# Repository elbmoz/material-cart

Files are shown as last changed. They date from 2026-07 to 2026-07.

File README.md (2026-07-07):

# Material Cart

物料搬运小车项目资料仓库，包含嵌入式控制程序、机械结构模型和 PCB 制板文件。

本项目面向竞赛机器人/物料搬运车场景，主要功能包括麦克纳姆轮底盘运动控制、Z 轴升降、舵机/机械臂抓取、视觉定位、二维码任务解析和按颜色/位置完成抓取放置流程。

## 仓库内容

```text
material-cart/
├── gc-z7-code/     STM32F407 控制程序与 Keil 工程
├── model/          SolidWorks 机械装配体与零件模型
├── 制板文件/       PCB Gerber 压缩包
└── README.md       项目说明
```

## 嵌入式工程

控制程序位于 `gc-z7-code/`，使用 STM32CubeMX 生成，目标芯片为 `STM32F407VETx`，工具链为 Keil MDK-ARM。

常用入口：

| 文件/目录 | 说明 |
|---|---|
| `gc-z7-code/MDK-ARM/gc.uvprojx` | Keil uVision 工程文件 |
| `gc-z7-code/gc.ioc` | STM32CubeMX 配置文件 |
| `gc-z7-code/Core/Inc/` | 用户头文件 |
| `gc-z7-code/Core/Src/` | 用户源文件 |
| `gc-z7-code/Drivers/` | STM32 HAL 与 CMSIS 驱动 |
| `gc-z7-code/MDK-ARM/gc/` | Keil 编译输出目录 |

### 打开与编译

1. 安装 Keil MDK-ARM。
2. 打开 `gc-z7-code/MDK-ARM/gc.uvprojx`。
3. 选择目标工程后编译。
4. 通过 ST-Link / SWD 下载到 STM32F407 控制板。

当前仓库未配置命令行构建脚本，建议直接使用 Keil uVision 编译和烧录。

### 主要模块

| 模块 | 作用 |
|---|---|
| `Motor_Move.c/.h` | 底盘运动、麦克纳姆轮解算、Z 轴升降控制 |
| `GC_Chassis_Control.c/.h` | 底盘 PID、定距直行、原地转向、视觉定位控制 |
| `PID.c/.h` | 通用 PID 算法 |
| `zhangdatou.c/.h` | 步进电机驱动通信 |
| `HWT101.c/.h` | HWT101 IMU 姿态角读取 |
| `serial.c/.h` | 视觉模块串口通信 |
| `LobotServoController.c/.h` | 幻尔串口舵机控制 |
| `huaner_servo.c/.h` | 舵机预设动作 |
| `ServoMotorControl.c/.h` | 视觉辅助的舵机精定位 |
| `QRcode.c/.h` | 二维码任务读取 |
| `action.c/.h` | 比赛动作流程编排 |

## 机械模型

机械模型位于 `model/`，主要包含 SolidWorks 装配体和零件文件：

| 类型 | 扩展名 | 说明 |
|---|---|---|
| 装配体 | `.SLDASM` | 小车整体、局部机构装配 |
| 零件 | `.SLDPRT` | 结构件、支架、轮组、机械臂等 |
| 通用模型 | `.stp` | 可跨 CAD 软件导入的模型文件 |

建议使用 SolidWorks 打开根装配体，例如 `model/1.SLDASM` 或 `model/xyz版.SLDASM`。

## 制板文件

PCB 制板文件位于 `制板文件/`，目前包含多个 Gerber 压缩包：

| 文件 | 说明 |
|---|---|
| `Gerber_主板.zip` | 主控板制板文件 |
| `Gerber_openmv转接板.zip` | OpenMV 转接板制板文件 |
| `Gerber_塔吊转接板.zip` | 塔吊/机构转接板制板文件 |
| `Gerber_幻尔转接板.zip` | 幻尔舵机/模块转接板制板文件 |
| `Gerber_烧录转接板.zip` | 烧录转接板制板文件 |

下单制板前建议先用 Gerber 查看器检查层定义、孔位、板框和丝印。

## 硬件与通信简表

| 外设/接口 | 用途 |
|---|---|
| USART1 | 步进电机驱动通信 |
| USART2 | HWT101 IMU |
| UART5 | 视觉模块 / 蓝牙调试通信 |
| USART6 | 幻尔串口舵机 |
| TIM2 | 1 ms 定时中断 |
| TIM3 | PWM 舵机输出 |
| PE7 | 限位开关输入 |

## 使用建议

- 修改 STM32 外设配置时，优先编辑 `gc-z7-code/gc.ioc` 并通过 STM32CubeMX 重新生成。
- 自定义代码应尽量放在 `/* USER CODE BEGIN */` 和 `/* USER CODE END */` 区域内，避免重新生成时被覆盖。
- 机械模型包含较多中文文件名，跨系统传输时注意编码和路径兼容性。
- 当前仓库保留了部分 Keil 编译产物，便于复现原始工程状态；后续如果只维护源码，可以再添加 `.gitignore` 精简仓库。

## 许可

仓库当前未声明开源许可证。未经项目成员确认前，请勿默认用于商业发布或二次分发。

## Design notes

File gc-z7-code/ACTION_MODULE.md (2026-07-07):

# action 模块说明

本文用于快速理解 `Core/Src/action.c` 和 `Core/Inc/action.h` 的作用、对外接口和在 `GC_task.c` 中的调用方式。

## 1. 模块定位

`action` 模块是比赛动作编排层。

它不直接实现底层电机通信、PID 算法或舵机协议，而是把已有基础动作组合成完整比赛流程：

- 舵机预设动作：来自 `huaner_servo.h`
- Z 轴升降/回零：来自 `Motor_Move.h`
- 视觉找物块：来自 `ServoMotorControl.h`
- 底盘定位移动：来自 `GC_Chassis_Control.h`
- 动作等待：来自 `delay.h`

一句话理解：

```text
二维码任务 -> 视觉找物块 -> 抓到车上槽位 -> 从车上取出 -> 按颜色放地面 -> 再从地面回收到车上
```

## 2. 任务值含义

`action.c` 当前只处理 3 个颜色任务：

```c
#define ACTION_QRCODE_TASK_COUNT 3U
#define ACTION_PLACE_SIDE_OFFSET_MM 152.0f
```

任务值必须是 `1~3`，非法值会被跳过。

地面放置位置映射：

| task | 含义 | 地面 X 目标位置 |
|---|---|---|
| `1` | 红色 / 左侧 | `-152mm` |
| `2` | 绿色 / 中间 | `0mm` |
| `3` | 蓝色 / 右侧 | `+152mm` |

注意：`task1/task2/task3` 表示颜色任务顺序，不直接表示车上槽位。车上槽位由数组下标决定：

```text
第 1 个 task -> 车上槽 1
第 2 个 task -> 车上槽 2
第 3 个 task -> 车上槽 3
```

## 3. 推荐在 GC_task 中调用的接口

这些是 `action.h` 中最适合流程状态机调用的高级接口。

### Action_RunQRCodeTasks

```c
void Action_RunQRCodeTasks(uint8_t task1, uint8_t task2, uint8_t task3);
```

作用：按二维码给出的 3 个颜色任务，依次视觉找物块并抓到车上 1/2/3 槽。

内部流程：

```text
for each task:
  1. 判断 task 是否为 1~3
  2. ServoMotorVision_Calibrate(task) 视觉找对应颜色
  3. 调用 zhuafang1/2/3() 放到对应车槽
```

典型用途：物料盘抓取阶段。

### Action_PlaceLoadedQRCodeTasks1

```c
void Action_PlaceLoadedQRCodeTasks1(uint8_t task1, uint8_t task2, uint8_t task3);
```

作用：把车上 1/2/3 槽的物块取出来，按颜色放到地面左/中/右位置。

内部流程：

```text
for each task:
  1. 从车上第 i 个槽取物块
  2. 根据 task 计算地面 X 位置
  3. FieldPos_Block() 横向移动到目标位置
  4. 使用第一套高度放到地面
```

第一套放置高度中，Z 轴下降较深：

```c
ZAxis_MoveRelative(-13000, 200, 4000);
```

典型用途：第一轮地面放置。

### Action_PlaceLoadedQRCodeTasks2

```c
void Action_PlaceLoadedQRCodeTasks2(uint8_t task1, uint8_t task2, uint8_t task3);
```

作用：和 `Action_PlaceLoadedQRCodeTasks1()` 类似，也是把车上物块放到地面指定颜色位置。

区别：使用第二套放置高度，Z 轴下降较浅：

```c
ZAxis_MoveRelative(-7000, 200, 4000);
```

典型用途：第二轮放置或叠放阶段。

### Action_RecoverGroundQRCodeTasks

```c
void Action_RecoverGroundQRCodeTasks(uint8_t task1, uint8_t task2, uint8_t task3);
```

作用：按二维码顺序，从地面左/中/右位置把物块抓回车上 1/2/3 槽。

内部特点：

- 先用 `Action_GetLastPlaceX()` 推算当前底盘停在最后一次放置位置。
- 再按任务顺序移动到对应地面位置。
- 第一个回收动作走 `Action_GrabRecoverFirstToCarSlot()`。
- 后续回收动作走 `zhuafang8/9/10()`。

典型用途：地面物块回收到车上。

## 4. 暴露的底层动作脚本

这些函数也在 `action.h` 中暴露，但更适合单动作调试，不建议在正式流程里到处直接调用。

| 接口 | 作用 |
|---|---|
| `zhuafang1()` | 地面抓取并放到车上槽 1 |
| `zhuafang2()` | 地面抓取并放到车上槽 2 |
| `zhuafang3()` | 地面抓取并放到车上槽 3，末尾使用 `kanche2()` |
| `zhuafang4()` | 旧版较长组合动作，主流程基本未直接使用 |
| `zhuafang5()` | 槽 2 相关短动作，偏调试 |
| `zhuafang6()` | 槽 3 相关短动作，偏调试 |
| `zhuafang7()` | 视觉/底盘校准前准备动作：Z 轴回零、下降、看地面、松爪、servo13 回零 |
| `zhuafang8()` | 从地面抓回并放到车上槽 1 |
| `zhuafang9()` | 从地面抓回并放到车上槽 2 |
| `zhuafang10()` | 从地面抓回并放到车上槽 3，末尾使用 `kanche2()` |

## 5. 在 GC_task 中的调用方式

`Action_*` 接口都是阻塞式动作。调用后会执行完整机械动作，动作没做完不会返回。

因此在 `GC_task.c` 的 `case` 中调用时，必须调用完立刻切换到下一个状态，避免下一次 `GC_Task_Run()` 重复执行同一动作。

示例：

```c
#include "action.h"

case GC_wuliaopan1:
    Action_RunQRCodeTasks(gc_qr1, gc_qr2, gc_qr3);
    GC_Task_EnterState(GC_kaojinA1);
    break;
```

不推荐这样写：

```c
case GC_wuliaopan1:
    Action_RunQRCodeTasks(gc_qr1, gc_qr2, gc_qr3);
    break;
```

因为状态没有切走，下一次进入 `GC_Task_Run()` 还会再次执行抓取动作。

## 6. 二维码值传入 GC_task 的建议方式

`main.c` 当前可以通过 `QRcode_WaitTaskGroupsAndStop()` 获取 6 个二维码任务。

建议在 `GC_task.c` 中保存这些值：

```c
static uint8_t gc_qr1, gc_qr2, gc_qr3;
static uint8_t gc_qr4, gc_qr5, gc_qr6;

void GC_Task_SetQRCodeTasks(uint8_t t1, uint8_t t2, uint8_t t3,
                             uint8_t t4, uint8_t t5, uint8_t t6)
{
    gc_qr1 = t1;
    gc_qr2 = t2;
    gc_qr3 = t3;
    gc_qr4 = t4;
    gc_qr5 = t5;
    gc_qr6 = t6;
}
```

并在 `GC_task.h` 中声明：

```c
void GC_Task_SetQRCodeTasks(uint8_t t1, uint8_t t2, uint8_t t3,
                             uint8_t t4, uint8_t t5, uint8_t t6);
```

`main.c` 扫码完成后调用：

```c
GC_Task_SetQRCodeTasks((uint8_t)main_qrcode_task1,
                       (uint8_t)main_qrcode_task2,
                       (uint8_t)main_qrcode_task3,
                       (uint8_t)main_qrcode_task4,
                       (uint8_t)main_qrcode_task5,
                       (uint8_t)main_qrcode_task6);
```

之后 `GC_task.c` 中就可以直接使用：

```c
Action_RunQRCodeTasks(gc_qr1, gc_qr2, gc_qr3);
Action_PlaceLoadedQRCodeTasks1(gc_qr1, gc_qr2, gc_qr3);
Action_RecoverGroundQRCodeTasks(gc_qr1, gc_qr2, gc_qr3);

Action_RunQRCodeTasks(gc_qr4, gc_qr5, gc_qr6);
Action_PlaceLoadedQRCodeTasks2(gc_qr4, gc_qr5, gc_qr6);
```

## 7. 可参考的两轮流程

当前 `main.c` 中已有类似流程，可以迁移到 `GC_task.c`：

```text
第一轮 task1~3:
  Action_RunQRCodeTasks
  VisionPrecision_Calibrate
  Action_PlaceLoadedQRCodeTasks1
  Action_RecoverGroundQRCodeTasks
  Action_PlaceLoadedQRCodeTasks1

第二轮 task4~6:
  Action_RunQRCodeTasks
  VisionPrecision_Calibrate
  Action_PlaceLoadedQRCodeTasks1
  Action_RecoverGroundQRCodeTasks
  VisionPrecision_Calibrate
  Action_PlaceLoadedQRCodeTasks2
```

## 8. 接手时优先检查的参数

`action` 模块的大部分问题不是语法错误，而是动作参数和实际机械结构不匹配。

优先检查：

- `ACTION_PLACE_SIDE_OFFSET_MM = 152.0f` 是否对应实际左/中/右间距。
- `ZAxis_MoveRelative()` 的下降/上升脉冲是否安全。
- `servo13_Home(backOffMs)` 的回退时间是否合适。
- `fangche1/2/3()`、`kanche()`、`kanche2()`、`kandi()` 的舵机位置是否和机械臂实际位置一致。
- `Action_PlaceLoadedQRCodeTasks1()` 和 `Action_PlaceLoadedQRCodeTasks2()` 的高度差是否对应第一轮/第二轮需求。

## 9. 总结

正式流程中优先调用：

```c
Action_RunQRCodeTasks(...)
Action_PlaceLoadedQRCodeTasks1(...)
Action_PlaceLoadedQRCodeTasks2(...)
Action_RecoverGroundQRCodeTasks(...)
```

单独调试机械动作时再调用：

```c
zhuafang1() ~ zhuafang10()
```

在 `GC_task.c` 中，每次调用一个 `Action_*` 后都应立即 `GC_Task_EnterState(next_state)`，避免重复执行同一个阻塞动作。

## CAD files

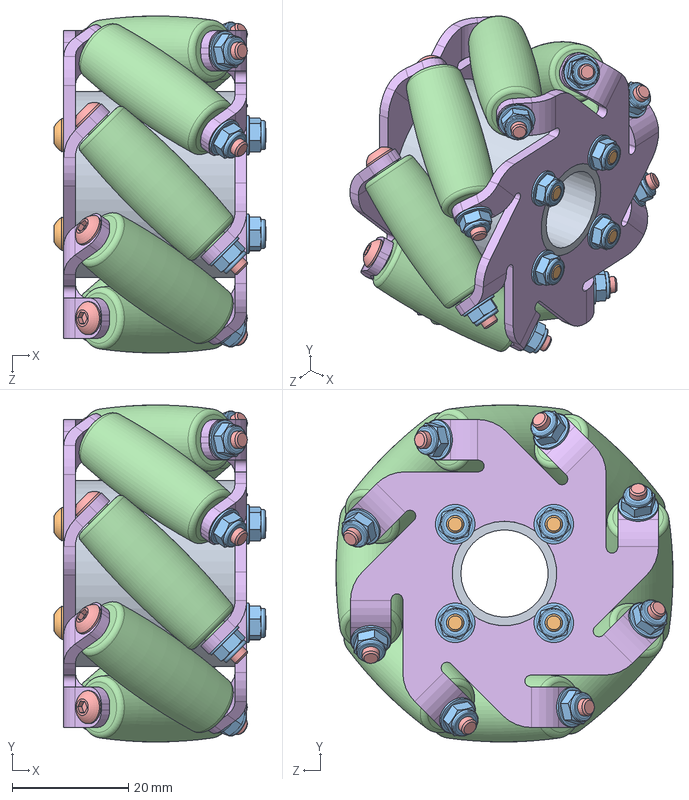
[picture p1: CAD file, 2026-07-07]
model/轮.SLDASM
36.5 x 58.0 x 58.0 mm
中轴
短螺丝 x 4
防松螺丝 x 12
滚轮1 x 8
长螺丝 x 8
支持架 x 2

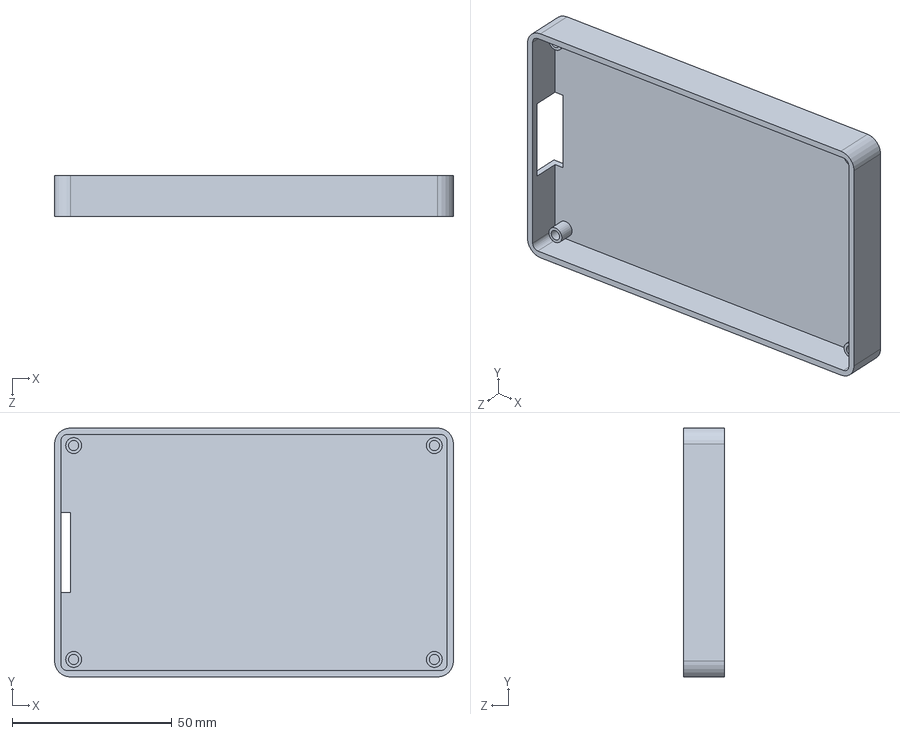
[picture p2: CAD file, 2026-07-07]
model/显示屏.SLDPRT
125.0 x 78.0 x 13.0 mm

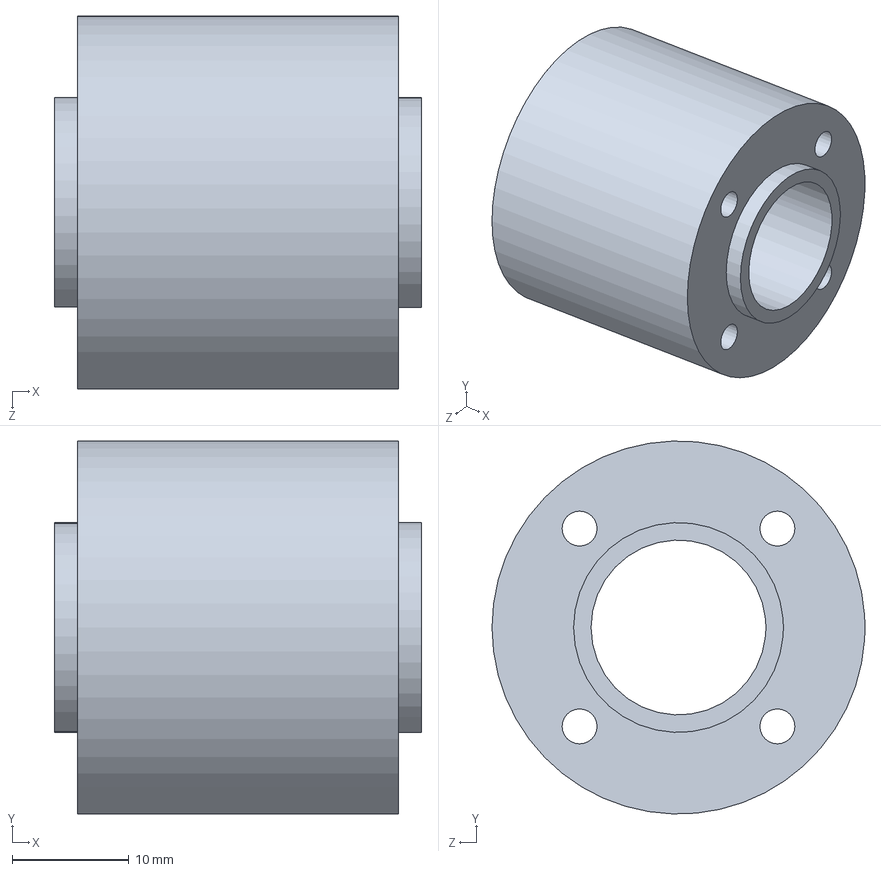
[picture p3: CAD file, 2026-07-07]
model/中轴.SLDPRT
31.5 x 32.0 x 32.0 mm

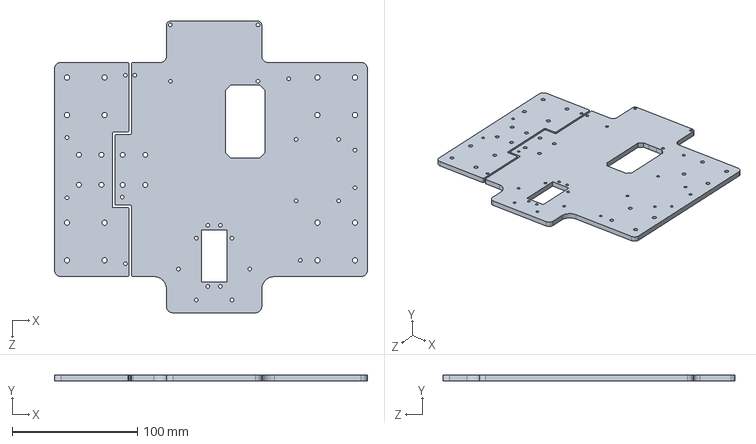
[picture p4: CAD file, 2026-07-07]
model/下板.SLDPRT
250.0 x 5.00 x 233.0 mm

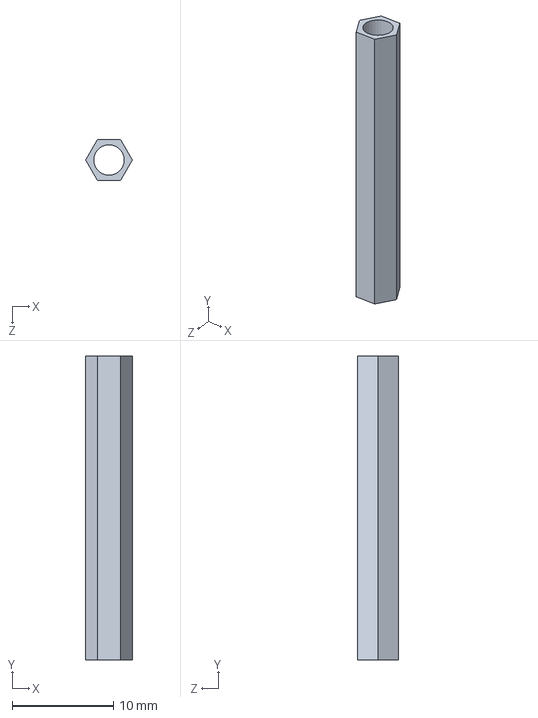
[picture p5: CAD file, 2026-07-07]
model/M3铜柱H30.SLDPRT
4.62 x 30.0 x 4.00 mm

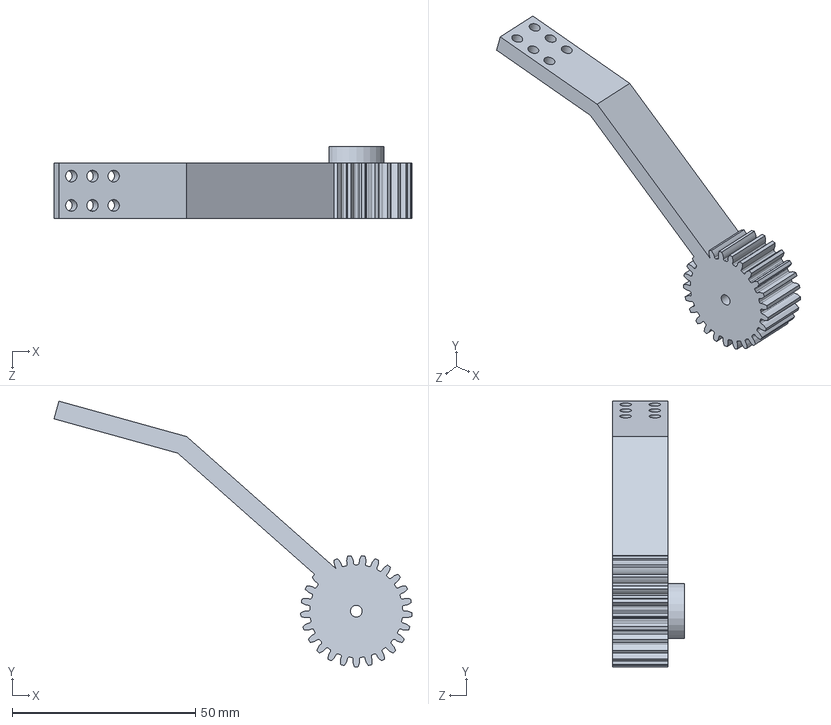
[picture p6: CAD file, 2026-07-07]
model/zuo.SLDPRT
97.6 x 72.4 x 19.5 mm

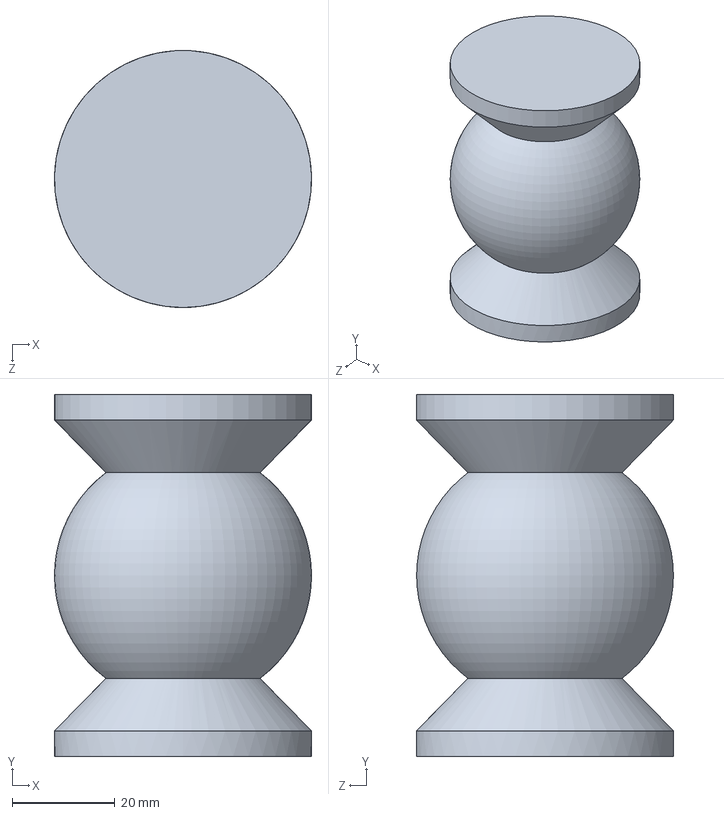
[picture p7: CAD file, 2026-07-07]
model/料子.SLDPRT
50.0 x 70.4 x 50.0 mm

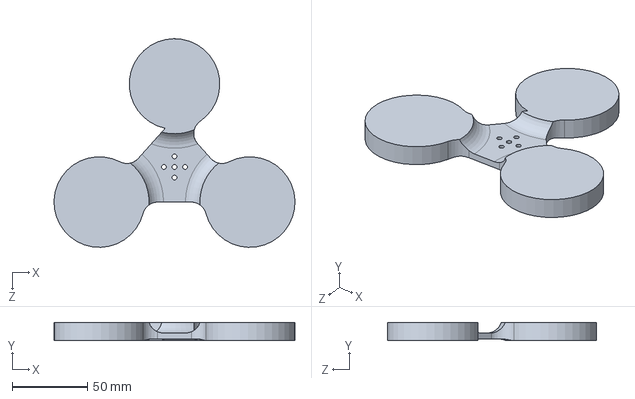
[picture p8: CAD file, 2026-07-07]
model/转盘4.SLDPRT
159.7 x 12.0 x 138.2 mm

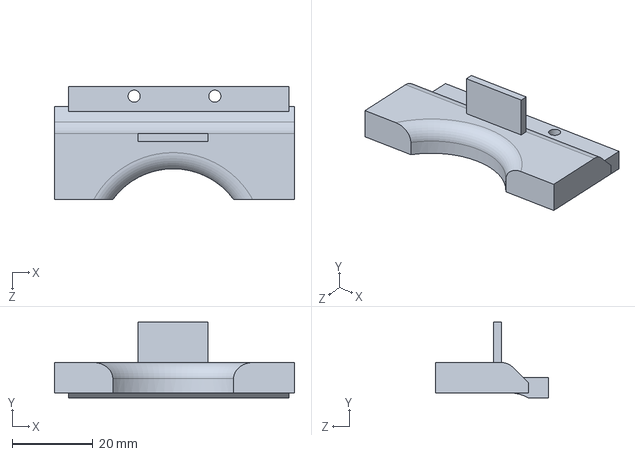
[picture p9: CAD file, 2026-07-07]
model/爪左.SLDPRT
59.5 x 18.8 x 28.0 mm

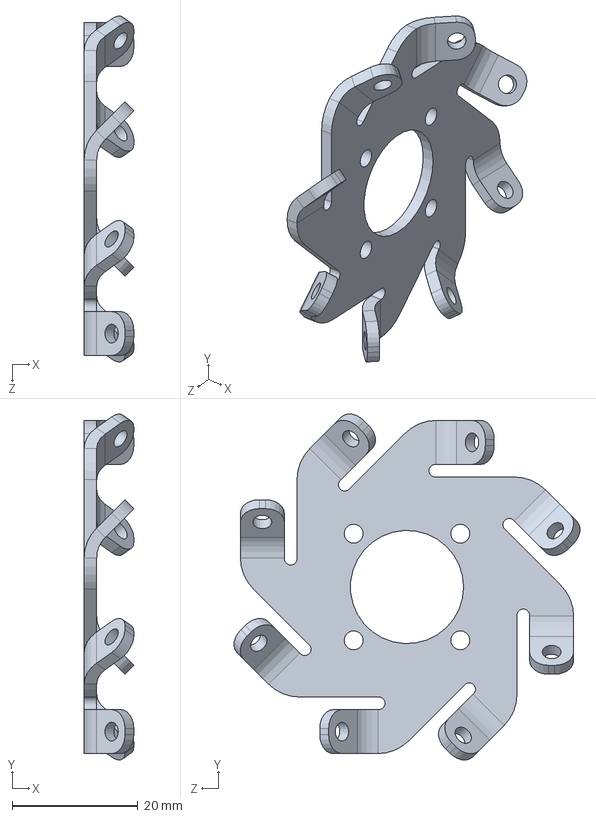
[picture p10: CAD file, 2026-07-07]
model/支持架.SLDPRT
7.91 x 55.0 x 55.0 mm

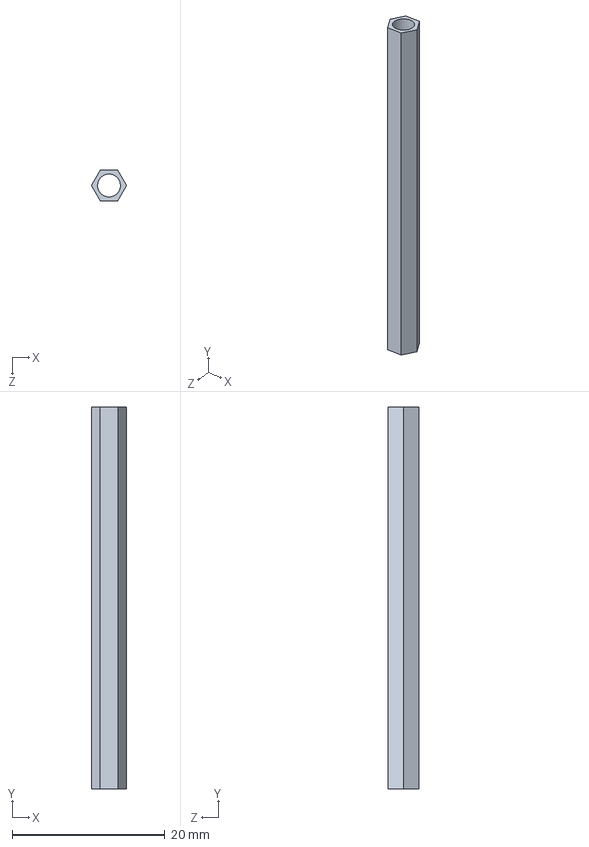
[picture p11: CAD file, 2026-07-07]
model/M3铜柱H45.SLDPRT
4.62 x 50.0 x 4.00 mm

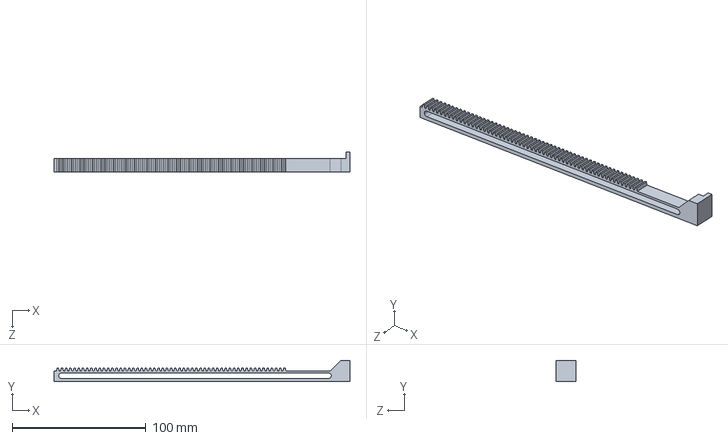
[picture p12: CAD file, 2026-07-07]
model/凯元齿条L188W10M1.SLDPRT
221.5 x 16.0 x 15.0 mm

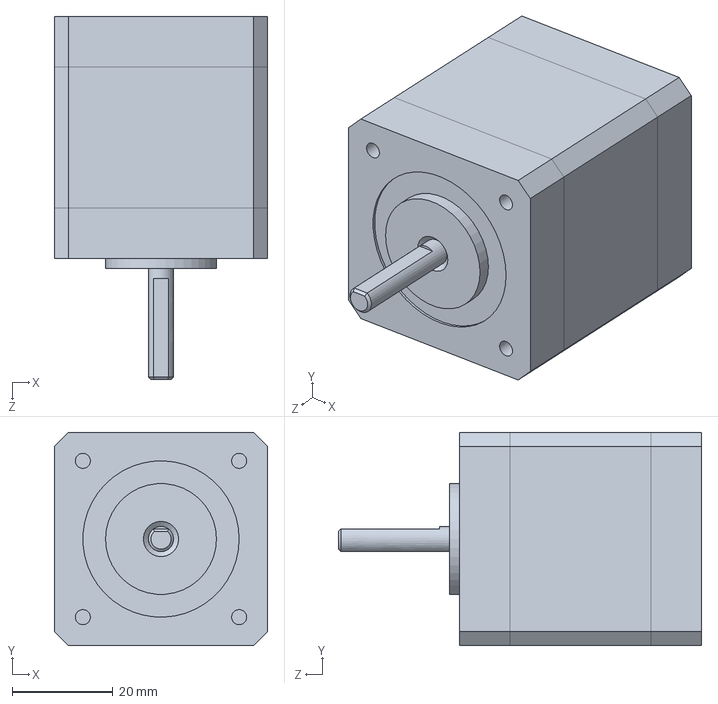
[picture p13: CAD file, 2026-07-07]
model/步进电机.SLDPRT
42.3 x 42.3 x 72.0 mm

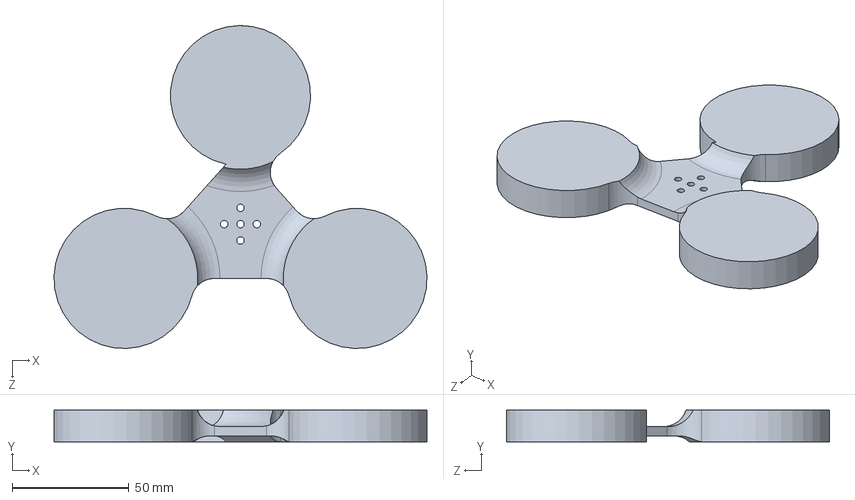
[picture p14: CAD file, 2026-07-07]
model/转盘5.SLDPRT
159.7 x 13.5 x 138.2 mm

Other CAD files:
model/开发板+托板_1.SLDASM
model/电池组.SLDASM
model/转.SLDASM
model/开发板+托板.SLDASM
model/M3铜柱H10.SLDPRT
model/M3铜柱H15.SLDPRT
model/M3铜柱H20.SLDPRT
model/M3铜柱H30.0.SLDPRT
model/M3铜柱H55.SLDPRT
model/MG995-MG996R Servo.SLDPRT
model/MG995-MG996R Servo.stp
model/openmv.SLDPRT
model/usb摄像头.SLDPRT
model/you.SLDPRT
model/zhu.SLDPRT
model/上板.SLDPRT
model/不锈钢固定.SLDPRT
model/不锈钢块.SLDPRT
model/伸臂 - 副本.SLDPRT
model/伸臂.SLDPRT
model/伸臂2.SLDPRT
model/伸臂3.SLDPRT
model/伸臂4.SLDPRT
model/全向轮.SLDPRT
model/划归.SLDPRT
model/单转盘.SLDPRT
model/同步轮M5.SLDPRT
model/喇叭.SLDPRT
model/固定上.SLDPRT
model/塔吊摄像头支撑架.SLDPRT
model/塔吊转接板.SLDPRT
model/夹子装.SLDPRT
model/夹子装右.SLDPRT
model/屏幕外壳.SLDPRT
model/开关.SLDPRT
model/开发板.SLDPRT
model/开发板托板.SLDPRT
model/扫码固定.SLDPRT
model/撑架.SLDPRT
model/撑架2.SLDPRT
model/支架.SLDPRT
model/支架步进.SLDPRT
model/料2.SLDPRT
model/树莓派.SLDPRT
model/横.SLDPRT
model/步进电机支架.SLDPRT
model/步进转盘.SLDPRT
model/滑块.SLDPRT
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

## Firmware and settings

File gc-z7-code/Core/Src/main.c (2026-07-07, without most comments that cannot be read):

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
/* Includes ------------------------------------------------------------------*/
#include "main.h"
#include "usart.h"
#include "gpio.h"

/* USER CODE BEGIN Includes */
#include "Motor_Move.h"
#include "serial.h"
#include "HWT101.h"
#include "GC_Chassis_Control.h"
#include "delay.h"
#include "servo.h"
#include "QRcode.h"
#include "bluetooth.h"
#include "LobotServoController.h"
#include "action.h"
#include "huaner_servo.h"
#include "ServoMotorControl.h"
#include "encoder_f407.h"
#include "GC_task.h"
#include "WS2812.h"
#include "laser.h"
#include "screen.h"
/* USER CODE END Includes */

TIM_HandleTypeDef htim2;

/* USER CODE BEGIN PV */
static volatile uint8_t main_qrcode_task1 = 0U;
static volatile uint8_t main_qrcode_task2 = 0U;
static volatile uint8_t main_qrcode_task3 = 0U;
static volatile uint8_t main_qrcode_task4 = 0U;
static volatile uint8_t main_qrcode_task5 = 0U;
static volatile uint8_t main_qrcode_task6 = 0U;
static volatile uint8_t main_qrcode_ready = 0U;

/* USER CODE END PV */

void SystemClock_Config(void);
static void MX_TIM2_Init(void);
/**
  * @brief  The application entry point.
  * @retval int
  */
int main(void)
{
  /* MCU Configuration--------------------------------------------------------*/

  /* Reset of all peripherals, Initializes the Flash interface and the Systick. */
  HAL_Init();

  /* Configure the system clock */
  SystemClock_Config();

  /* Initialize all configured peripherals */
  MX_GPIO_Init();
  MX_UART4_Init();
  MX_UART5_Init();
	
  MX_USART1_UART_Init();
  MX_USART2_UART_Init();
  MX_USART3_UART_Init();
  MX_USART6_UART_Init();
  MX_TIM2_Init();
  /* USER CODE BEGIN 2 */
  HAL_Delay(200);
  DWT_Delay_Init();
  WS2812_Init();
  Encoder_init();
  Motor_Init(&huart1);
  Enable();
  /* QR code reception is started in GC_saoma by GC_Task_ReadQRCodeTasks(). */

  
  /* Vision serial reception starts after QR code scanning in GC_task. */
  HWT101_Init(&huart2);
  LobotServo_Init();
  GC_Task_Init();
	fangche1();
	
  WS2812_SetRGB(0U, 20U, 0U);
  WS2812_Rainbow(WS2812_LED_COUNT, 0U, 255U);
	//	HAL_UART_Transmit(&huart5, (uint8_t *)"hi", 2, HAL_MAX_DELAY);
	//servo13_Home(75);
	
#if 1
  if (ZAxis_Home(1000, 200, 5000) != HAL_OK) {
    Error_Handler();
  }
  delay_ms(10);
  ZAxis_MoveRelative(-1000, 200, 1000);
delay_ms(1000);
#endif
  
  if (HAL_TIM_Base_Start_IT(&htim2) != HAL_OK) {
    Error_Handler();
  }
	
fang();
//zhua();
  
  
  //kan();
//			delay_ms(500);
//  delay_ms(2000);
//	
  
  // ????,????????
	
	
//*******************************************************************************  cjh_6_7
//                  /*有用的代码，误删*/
//  //扫二维码
//  if (QRcode_WaitTaskGroupsAndStop(&main_qrcode_task1,
//                                   &main_qrcode_task2,
//                                   &main_qrcode_task3,
//                                   &main_qrcode_task4,
//                                   &main_qrcode_task5,
//                                   &main_qrcode_task6,
//                                   &main_qrcode_ready) != HAL_OK) {
//    Error_Handler();
//  }



//	fang();
//	delay_ms(1000);
 //Serial_Init(&huart5);
//                     /*第一圈*/
//  //抓物块
//  Action_RunQRCodeTasks_Pos(1,
//                        2,
//                       3);



//  //视觉矫正
//  VisionPrecision_Calibrate();
////  //抓车上的物块到地面上
//  Action_PlaceLoadedQRCodeTasks1(1,
//                              2,
//                              3);

//  //放物块回车上
//  Action_RecoverGroundQRCodeTasks((uint8_t)main_qrcode_task1,
//                                (uint8_t)main_qrcode_task2,
//                                (uint8_t)main_qrcode_task3);
//  //抓车上的物块到地面上
//  Action_PlaceLoadedQRCodeTasks1((uint8_t)main_qrcode_task1,
//                              (uint8_t)main_qrcode_task2,
//                              (uint8_t)main_qrcode_task3);
//				/*第一圈结束*/

//				/*第二圈*/
//  //抓物块
//  Action_RunQRCodeTasks((uint8_t)main_qrcode_task4,
//                        (uint8_t)main_qrcode_task5,
//                        (uint8_t)main_qrcode_task6);
//  //视觉矫正
//  VisionPrecision_Calibrate();
//  //抓车上的物块到地面上
//  Action_PlaceLoadedQRCodeTasks1((uint8_t)main_qrcode_task4,
//                              (uint8_t)main_qrcode_task5,
//                              (uint8_t)main_qrcode_task6);
//  //放物块回车上
//  Action_RecoverGroundQRCodeTasks((uint8_t)main_qrcode_task4,
//                                (uint8_t)main_qrcode_task5,
//                                (uint8_t)main_qrcode_task6);
//  //视觉矫正
//Serial_Init(&huart5);
//  VisionPrecision_Calibrate2();
//  //抓车上的物块叠放到地面上
// Action_PlaceLoadedQRCodeTasks2(1,
//                              2,
//                              3);
//                        /*截止*/
//********************************************************************************


//		delay_ms(100);
//zhuafang3();
//	Pos_zuoxie(200,2000,6000);
////	delay_ms(1000);
//	Pos_RunStraight(150,200,6000);
////	Pos_RunStraight(150,200,6000);
////	Pos_RunStraight(150,200,6000);
////	Pos_RunStraight(150,200,20000);
//	
////	delay_ms(1000);
////	InPlaceTurn_Block(&in_place_turn, -2.0f);
////	delay_ms(100);
////	//saoma
////	
////	//liaopan
////	Pos_RunStraight(150,200,6000);
////	Pos_RunStraight(100,1000,1800);
			//Pos_RunStraight(150,2000,1000);
//	
//	
//	//delay_ms(1000);
//	//CarStraight_Block(&car_straight, 1000.0f, 0.0f, (float)global_angle); // 
  /* USER CODE END 2 */

  /* Infinite loop */
  /* USER CODE BEGIN WHILE */
  uint32_t last_bt_tick = HAL_GetTick();
//HAL_UART_Transmit(&huart5, (uint8_t *)"hi", 2, HAL_MAX_DELAY);

//FieldPos_Block(&field_pos, 200.0f, 200.0f, -90.0f);

		//Pos_RunRight(200,2000,2000);
		//Pos_RunLeft(200,2000,1000);
		//Pos_RunRight(200,2000,1000);
		//Pos_RunLeft(200,2000,1200);
	//Laser_On();
//	Screen_TestSend();
//	Screen_TestSend();
	
	//zhua();
	//fang();
//	delay_ms(2000);
//	
//	Serial_Init(&huart5);
//	
//	VisionPrecision_Calibrate();
//	Action_PlaceLoadedQRCodeTasks1(1U,2U,3U);
                             
	//Pos_Run(R,200,2000,1200);
	//WS2812_SetRGB(0U, 20U, 0U);
	
  while (1)
  {
    /* USER CODE END WHILE */
    pit_control();
    /* USER CODE BEGIN 3 */
    if ((GC_Task_GetState() != GC_WAIT_BTN) &&
        (GC_Task_GetState() != GC_DONE) &&
        (GC_Task_GetState() != GC_FAIL)) {
      WS2812_BluePurpleFlow(40U, 255U);
    }
    //GC_Task_Run();
		
		GC_Task_Run_Pos();
		
  }
  /* USER CODE END 3 */
}

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
/* USER CODE BEGIN 4 */
void HAL_TIM_Base_MspInit(TIM_HandleTypeDef* htim_base)
{
  if(htim_base->Instance==TIM2)
  {
    __HAL_RCC_TIM2_CLK_ENABLE();

    HAL_NVIC_SetPriority(TIM2_IRQn, 1, 0);
    HAL_NVIC_EnableIRQ(TIM2_IRQn);
  }
}

void HAL_TIM_PeriodElapsedCallback(TIM_HandleTypeDef *htim)
{
  if (htim->Instance == TIM2) {
    pit_1ms_pending++;
  }
}

void HAL_UART_RxCpltCallback(UART_HandleTypeDef *huart)
{
  Motor_UART_RxCpltCallback(huart);
  serial_Handler(huart);
  QRcode_UART_RxCpltCallback(huart);

  hwt_Handler(huart);
}
/* USER CODE END 4 */
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


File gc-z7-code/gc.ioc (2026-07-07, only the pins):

Mcu.UserName=STM32F407VETx
PA10.Signal=USART1_RX
PA13.Signal=SYS_JTMS-SWDIO
PA14.Signal=SYS_JTCK-SWCLK
PA2.Signal=USART2_TX
PA3.Signal=USART2_RX
PA9.Signal=USART1_TX
PB10.Signal=USART3_TX
PB11.Signal=USART3_RX
PC10.Signal=UART4_TX
PC11.Signal=UART4_RX
PC12.Signal=UART5_TX
PC6.Signal=USART6_TX
PC7.Signal=USART6_RX
PD2.Signal=UART5_RX
PE7.Signal=GPIO_Input

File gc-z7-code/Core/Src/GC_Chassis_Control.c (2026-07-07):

#include "GC_Chassis_Control.h"
#include "Motor_Move.h"
#include "HWT101.h"
#include "serial.h"
#include "delay.h"
#include "bluetooth.h"
#include "screen.h"
#include "ServoMotorControl.h"
#include "encoder_f407.h"
#include "huaner_servo.h"
#include "action.h"

CarStraight_Cascade car_straight;
InPlaceTurn_Cascade in_place_turn;
InPlaceTurnMm_Cascade in_place_turn_mm;
VisionPrecision_Cascade vision_precision;
FieldPos_Cascade field_pos;

volatile uint32_t pit_1ms_pending = 0;
volatile uint32_t system_count = 0;

uint16_t chassis_motor_slope = 10U;

#define VISION_PRECISION_START_DELAY_MS      10U
#define VISION_PRECISION_CALIBRATE_TIMEOUT_MS 50000U

static uint8_t pid_config_done = 0U;
static float mm_per_count;

/* Tune with: new = old * measured_mm / target_mm. */
#define FIELD_POS_X_MM_CORRECTION 1.05f
#define FIELD_POS_Y_MM_CORRECTION 3.99f
#define ENABLE_VISION_Y_AXIS_PID 1U

static float NormalizeAngle(float angle)
{
    while (angle > 180.0f) angle -= 360.0f;
    while (angle < -180.0f) angle += 360.0f;
    return angle;
}

static float PositionToMm(int32_t position)
{
    return (float)position * mm_per_count;
}

static HAL_StatusTypeDef RefreshAllPositions(void)
{
    static const uint8_t addr[4] = {LF, LB, RF, RB};
    for (int i = 0; i < 4; i++) {
        HAL_StatusTypeDef s = Motor_RequestPositionUpdate(addr[i]);
        if (s != HAL_OK) return s;
        uint32_t t0 = HAL_GetTick();
        while (Motor_IsComBusy()) {
            if (HAL_GetTick() - t0 > 50U) return HAL_TIMEOUT;
        }
        s = Motor_GetLastComStatus();
        if (s != HAL_OK) return s;
    }
    return HAL_OK;
}

static HAL_StatusTypeDef ReadWheelPositions(int32_t *lf, int32_t *lb,
                                            int32_t *rf, int32_t *rb)
{
    HAL_StatusTypeDef s;
    if (lf == NULL || lb == NULL || rf == NULL || rb == NULL) return HAL_ERROR;

    s = Motor_ReadPosition(LF, lf, NULL);  if (s != HAL_OK) return s;  car_straight.lf_position = *lf;
    s = Motor_ReadPosition(LB, lb, NULL);  if (s != HAL_OK) return s;  car_straight.lb_position = *lb;
    s = Motor_ReadPosition(RF, rf, NULL);  if (s != HAL_OK) return s;  car_straight.rf_position = *rf;
    s = Motor_ReadPosition(RB, rb, NULL);  if (s != HAL_OK) return s;  car_straight.rb_position = *rb;
    return HAL_OK;
}

static HAL_StatusTypeDef ReadAverageDistance(float *dist)
{
    int32_t lf, lb, rf, rb;
    if (dist == NULL) return HAL_ERROR;
    HAL_StatusTypeDef s = ReadWheelPositions(&lf, &lb, &rf, &rb);
    if (s != HAL_OK) return s;
    *dist = (PositionToMm(lf) + PositionToMm(lb) - PositionToMm(rf) - PositionToMm(rb)) * 0.25f;
    return HAL_OK;
}

static void ChassisSetWheels(float lf, float rf, float lb, float rb, float max_spd)
{
    lf = LimitValue(lf, -max_spd, max_spd);
    rf = LimitValue(rf, -max_spd, max_spd);
    lb = LimitValue(lb, -max_spd, max_spd);
    rb = LimitValue(rb, -max_spd, max_spd);

    Motor_SpeedControl(LF, (lf >= 0) ? DIRECTION_POSITIVE : DIRECTION_NEGATIVE, chassis_motor_slope, (uint16_t)Abs(lf), SNF_ENABLE);
    delay_ms(1);
    Motor_SpeedControl(RF, (rf >= 0) ? DIRECTION_NEGATIVE : DIRECTION_POSITIVE, chassis_motor_slope, (uint16_t)Abs(rf), SNF_ENABLE);
    delay_ms(1);
    Motor_SpeedControl(LB, (lb >= 0) ? DIRECTION_POSITIVE : DIRECTION_NEGATIVE, chassis_motor_slope, (uint16_t)Abs(lb), SNF_ENABLE);
    delay_ms(1);
    Motor_SpeedControl(RB, (rb >= 0) ? DIRECTION_NEGATIVE : DIRECTION_POSITIVE, chassis_motor_slope, (uint16_t)Abs(rb), SNF_ENABLE);
    delay_ms(1);
    Motor_SyncStart(); delay_ms(1);
}

void PID_Config_Init(void)
{
    if (pid_config_done) return;
    pid_config_done = 1U;

    /* ============ CarStraight ============ */
    car_straight.max_speed                 = 200.0f;
    car_straight.max_turn_speed            = 300.0f;
    car_straight.distance_deadband         = 3.0f;
    car_straight.yaw_deadband              = 1.0f;
    car_straight.position_integral_limit   = 1000.0f;
    car_straight.angle_integral_limit      = 100.0f;
    car_straight.wheel_diameter_mm         = 75.0f;
    car_straight.position_counts_per_rev   = 65536.0f;
    car_straight.max_y_speed               = 300.0f;
    car_straight.vy_slope                  = 10;
    car_straight.last_status               = HAL_OK;
    chassis_motor_slope = 200U;
    
    mm_per_count = 3.1415926f * car_straight.wheel_diameter_mm
                 / car_straight.position_counts_per_rev;

    {
        PID_Cycle *c = &car_straight.position_cycle;
        c->p = 0.9f;  c->i = 0.0f;  c->d = 0.3f;
        c->out_max = car_straight.max_speed;
        c->i_max   = car_straight.position_integral_limit;
        c->deadband = car_straight.distance_deadband;

        c->mode = PID_POSITION;
        PID_Cycle_Reset(c);
    }
    {
        PID_Cycle *c = &car_straight.angle_cycle;
        c->p = 0.4f;  c->i = 0.0f;  c->d = 0.0f;
        c->out_max = car_straight.max_turn_speed;
        c->i_max   = car_straight.angle_integral_limit;
        c->deadband = car_straight.yaw_deadband;

        c->mode = PID_POSITION;
        PID_Cycle_Reset(c);
    }

    /* ============ InPlaceTurn ============ */
    in_place_turn.max_turn_speed    = 200.0f;
    in_place_turn.max_wheel_speed   = 200.0f;
    in_place_turn.yaw_deadband      = 0.5f;
    in_place_turn.z_integral_limit  = 100.0f;
    in_place_turn.stable_count_limit = 10U;

    {
        PID_Cycle *c = &in_place_turn.z_cycle;
        c->p = 7.0f;  c->i = 0.1f;  c->d = 0.0f;
        c->out_max = in_place_turn.max_turn_speed;
        c->i_max   = in_place_turn.z_integral_limit;
        c->deadband = in_place_turn.yaw_deadband;

        c->mode = PID_POSITION;
        PID_Cycle_Reset(c);
    }

    /* ============ InPlaceTurnMm ============ */
    in_place_turn_mm.max_turn_speed    = 200.0f;
    in_place_turn_mm.max_wheel_speed   = 200.0f;
    in_place_turn_mm.min_turn_speed    = 30.0f;
    in_place_turn_mm.yaw_deadband      = 0.5f;
    in_place_turn_mm.z_integral_limit  = 100.0f;
    in_place_turn_mm.stable_count_limit = 10U;

    {
        PID_Cycle *c = &in_place_turn_mm.z_cycle;
        c->p = 7.0f;  c->i = 0.1f;  c->d = 0.0f;
        c->out_max = in_place_turn_mm.max_turn_speed;
        c->i_max   = in_place_turn_mm.z_integral_limit;
        c->deadband = in_place_turn_mm.yaw_deadband;

        c->mode = PID_POSITION;
        PID_Cycle_Reset(c);
    }

    /* ============ VisionPrecision ============ */
    vision_precision.max_x_speed      = 300.0f;
    vision_precision.max_y_speed      = 300.0f;
    vision_precision.max_rotate_speed = 120.0f;
    vision_precision.max_wheel_speed  = 450.0f;
    vision_precision.x_deadband       = 2.0f;
    vision_precision.y_deadband       = 2.0f;
    vision_precision.yaw_deadband     = 0.5f;
    vision_precision.stable_count_limit = 10U;
    vision_precision.data_timeout_limit = 10U;
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

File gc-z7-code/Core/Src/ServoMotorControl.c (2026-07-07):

#include "ServoMotorControl.h"
#include "LobotServoController.h"
#include "Motor_Move.h"
#include "delay.h"
#include "serial.h"
#include "huaner_servo.h"
ServoMotorVision_Cascade servo_motor_vision;

static uint8_t config_inited = 0U;

/* ─── 限流参数 ─── */
#define ENABLE_X_AXIS_PID       1U      /* 1: tune servo 0 X axis */
#define ENABLE_Y_AXIS_PID       1U      /* 0: tune X axis only, keep servo 13 stopped */
#define SERVO0_CMD_INTERVAL_MS   50U    /* moveServo 最小发送间隔 (ms) */
#define SERVO0_MIN_PWM           500U
#define SERVO0_MAX_PWM           2500U
#define SERVO0_SEARCH_MIN_PWM    1860U
#define SERVO0_SEARCH_MAX_PWM    2200U
#define SERVO0_SEARCH_STEP_PWM   20U
#define SERVO0_SEARCH_MOVE_MS    20U
#define SERVO0_SEARCH_DWELL_MS   120U
#define SERVO0_SEARCH_VALID_FRAMES 1U
#define SERVO0_SEARCH_START_SETTLE_MS 300U

/* ============ 参数初始化 ============ */

void ServoMotorVision_ConfigInit(void)
{
    if (config_inited) return;
    config_inited = 1U;

    servo_motor_vision.max_x_step          = 100.0f;
    servo_motor_vision.max_y_speed          = 1000.0f;
    servo_motor_vision.x_deadband           = 40.0f;
    servo_motor_vision.y_deadband           = 10.0f;
    servo_motor_vision.y_speed_deadband     = 200.0f;   /* |vy_ref|<100 即PWM在1500±100 */
    servo_motor_vision.stable_count_limit   = 10U;
    servo_motor_vision.data_timeout_limit   = 50U;
    servo_motor_vision.last_move_tick       = 0U;

    /* X轴PID — 舵机0 (180°位置控制) */
    {
        PID_Cycle *c = &servo_motor_vision.x_cycle;
        c->p       = 0.2f;
        c->i       = 0.0f;
        c->d       = 0.4f;
        c->out_max = servo_motor_vision.max_x_step;
        c->i_max   = servo_motor_vision.max_x_step;
        c->deadband = servo_motor_vision.x_deadband;
        c->mode    = PID_POSITION;
        PID_Cycle_Reset(c);
    }

    /* Y轴PID — 舵机13 (360°速度控制) */
    {
        PID_Cycle *c = &servo_motor_vision.y_cycle;
        c->p       = 10.0f;
        c->i       = 0.3f;
        c->d       = 61.0f;
        c->out_max = servo_motor_vision.max_y_speed;
        c->i_max   = servo_motor_vision.max_y_speed;
        c->deadband = servo_motor_vision.y_deadband;
        c->mode    = PID_POSITION;
        PID_Cycle_Reset(c);
    }
}

/* ============ 内部工具 ============ */

static uint16_t Servo0_ClampPwm(uint16_t pwm)
{
    if (pwm < SERVO0_MIN_PWM) return SERVO0_MIN_PWM;
    if (pwm > SERVO0_MAX_PWM) return SERVO0_MAX_PWM;
    return pwm;
}

void ServoMotorVision_MoveServo0(uint16_t pwm, uint16_t time_ms)
{
    uint16_t target = Servo0_ClampPwm(pwm);

    servo_motor_vision.servo0_target_pwm = target;
    moveServo(0, target, time_ms);
}

static void StopActuators(void)
{
    /* X轴: 舵机0 — 保持当前位置不动，不发新指令 */
    /* Y轴: 停舵机13 */
    servo13_SetSpeed(0);
}

static uint8_t ServoMotorVision_WaitForTarget(uint32_t wait_ms,
                                             uint32_t *last_frame,
                                             uint8_t *valid_count)
{
    extern void pit_control(void);
    uint32_t start = HAL_GetTick();

    if (last_frame == NULL || valid_count == NULL) {
        return 0U;
    }

    while ((uint32_t)(HAL_GetTick() - start) < wait_ms) {
        pit_control();
        if (servo_motor_vision.data_frame_counter != *last_frame) {
            *last_frame = servo_motor_vision.data_frame_counter;
            if (servo_motor_vision.data_valid) {
                if (*valid_count < SERVO0_SEARCH_VALID_FRAMES) {
                    (*valid_count)++;
                }
                if (*valid_count >= SERVO0_SEARCH_VALID_FRAMES) {
                    return 1U;
                }
            } else {
                *valid_count = 0U;
            }
        }
    }

    return 0U;
}

static void ServoMotorVision_SearchTarget(uint8_t color_task)
{
    uint16_t pwm = servo_motor_vision.servo0_target_pwm;
    int8_t direction = 1;
    uint32_t last_frame = 0U;
    uint8_t valid_count = 0U;

    if (pwm < SERVO0_SEARCH_MIN_PWM) {
        pwm = SERVO0_SEARCH_MIN_PWM;
    } else if (pwm > SERVO0_SEARCH_MAX_PWM) {
        pwm = SERVO0_SEARCH_MAX_PWM;
    }
    if (pwm >= (uint16_t)(SERVO0_SEARCH_MAX_PWM - SERVO0_SEARCH_STEP_PWM)) {
        direction = -1;
    }

    servo_motor_vision.enable = 0U;
    servo_motor_vision.finished = 1U;
    servo_motor_vision.vx_ref = 0.0f;
    servo_motor_vision.vy_ref = 0.0f;
    servo_motor_vision.data_valid = 0U;
    servo_motor_vision.data_frame_counter = 0U;
    servo_motor_vision.data_timeout_count = 0U;
    PID_Cycle_SetEnable(&servo_motor_vision.x_cycle, 0U);
    PID_Cycle_SetEnable(&servo_motor_vision.y_cycle, 0U);
    Vision_UART_StopStream();
    delay_ms(10);

    ServoMotorVision_MoveServo0(pwm, SERVO0_SEARCH_MOVE_MS);
    delay_ms(SERVO0_SEARCH_START_SETTLE_MS);
    servo_motor_vision.data_valid = 0U;
    servo_motor_vision.data_frame_counter = 0U;
    servo_motor_vision.data_timeout_count = 0U;
    last_frame = servo_motor_vision.data_frame_counter;
    valid_count = 0U;
    Vision_UART_StartTask(color_task);
    delay_ms(10);

    while (1) {
        ServoMotorVision_MoveServo0(pwm, SERVO0_SEARCH_MOVE_MS);

        if (ServoMotorVision_WaitForTarget(SERVO0_SEARCH_DWELL_MS,
                                            &last_frame,
                                            &valid_count)) {
            return;
        }

        if (direction > 0) {
            if ((uint16_t)(pwm + SERVO0_SEARCH_STEP_PWM) >= SERVO0_SEARCH_MAX_PWM) {
                pwm = SERVO0_SEARCH_MAX_PWM;
                direction = -1;
            } else {
                pwm = (uint16_t)(pwm + SERVO0_SEARCH_STEP_PWM);
            }
        } else {
            if (pwm <= (uint16_t)(SERVO0_SEARCH_MIN_PWM + SERVO0_SEARCH_STEP_PWM)) {
                pwm = SERVO0_SEARCH_MIN_PWM;
                direction = 1;
            } else {
                pwm = (uint16_t)(pwm - SERVO0_SEARCH_STEP_PWM);
            }
        }
    }
}

static void ApplyOutputs(ServoMotorVision_Cascade *smv)
{
#if ENABLE_X_AXIS_PID
    /* ── X轴 → 舵机0: 当前目标PWM按PID步长逐步修正 ── */
    {
        uint32_t now = HAL_GetTick();
        if (now - smv->last_move_tick >= SERVO0_CMD_INTERVAL_MS) {
            int32_t tmp = (int32_t)smv->servo0_target_pwm + (int32_t)smv->vx_ref;

            if (tmp < SERVO0_MIN_PWM)      tmp = SERVO0_MIN_PWM;
            else if (tmp > SERVO0_MAX_PWM) tmp = SERVO0_MAX_PWM;

            ServoMotorVision_MoveServo0((uint16_t)tmp, 80);
            smv->last_move_tick = now;
        }
    }
#endif

#if ENABLE_Y_AXIS_PID
    /* ── Y轴 → 舵机13 (360°连续舵机, 方向取反) ── */
    {
        int16_t speed = -(int16_t)smv->vy_ref;
        if (speed > 1000)  speed = 1000;
        if (speed < -1000) speed = -1000;
        servo13_SetSpeed(speed);
    }
#else
    servo13_SetSpeed(0);
#endif
}

/* ============ 生命周期 ============ */
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

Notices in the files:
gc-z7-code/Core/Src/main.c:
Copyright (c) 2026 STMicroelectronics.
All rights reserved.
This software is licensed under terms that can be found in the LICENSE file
